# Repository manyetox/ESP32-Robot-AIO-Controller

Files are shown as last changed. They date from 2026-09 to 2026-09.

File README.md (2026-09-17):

# Robot AIO ESP32 Controller

**Compact all-in-one ESP32 controller for RC cars, mobile robots and small combat robots.**

This PCB was designed to replace the usual collection of an ESP32 development board, multiple motor-driver modules, voltage regulators and large amounts of wiring with a single compact controller.

The board integrates an **ESP32-WROOM-32UE**, **four independent brushed DC motor drivers**, onboard power regulation, battery-voltage monitoring, programming/debug connections and additional GPIO into a **50 × 46.2 mm PCB**.

The controller has been **manufactured, hand-assembled and fully tested**, and the finished board is operational.

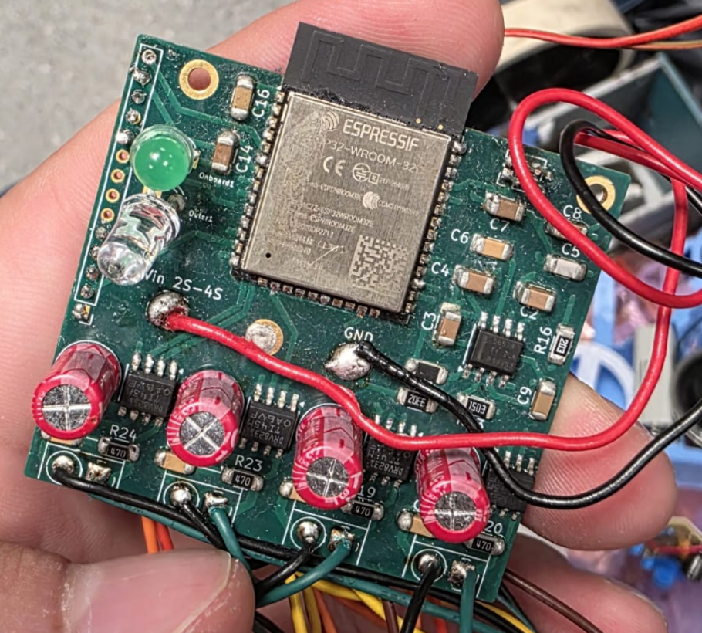
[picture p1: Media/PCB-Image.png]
Assembled Robot AIO Controller


> **Status:** Hardware tested and working
> **PCB:** 8-layer, 50 × 46.2 mm
> **Controller:** ESP32-WROOM-32UE
> **Motor channels:** 4 × bidirectional brushed DC
> **Battery:** 2S–4S
> **Application:** RC cars, mobile robots and small combat robots

---

## Why I Built This

Small competition robots often end up containing several separate modules:

* ESP32/Arduino development board
* multiple H-bridge motor drivers
* voltage regulator
* battery-monitoring circuit
* programming hardware
* connectors
* large amounts of point-to-point wiring

This works, but it takes space, adds failure points and makes the electrical system much harder to package cleanly inside a small robot.

The goal of **Robot AIO** was to integrate the essential electronics of a small mobile robot onto one board.

It was originally designed with **Robot Wars / combat robotics and RC-car projects** in mind, where compact packaging, fast assembly and simple motor control are particularly useful.

---

## Hardware Images

The final PCB shown above has been assembled and tested successfully. The repository also includes the design views below.

### PCB Layout

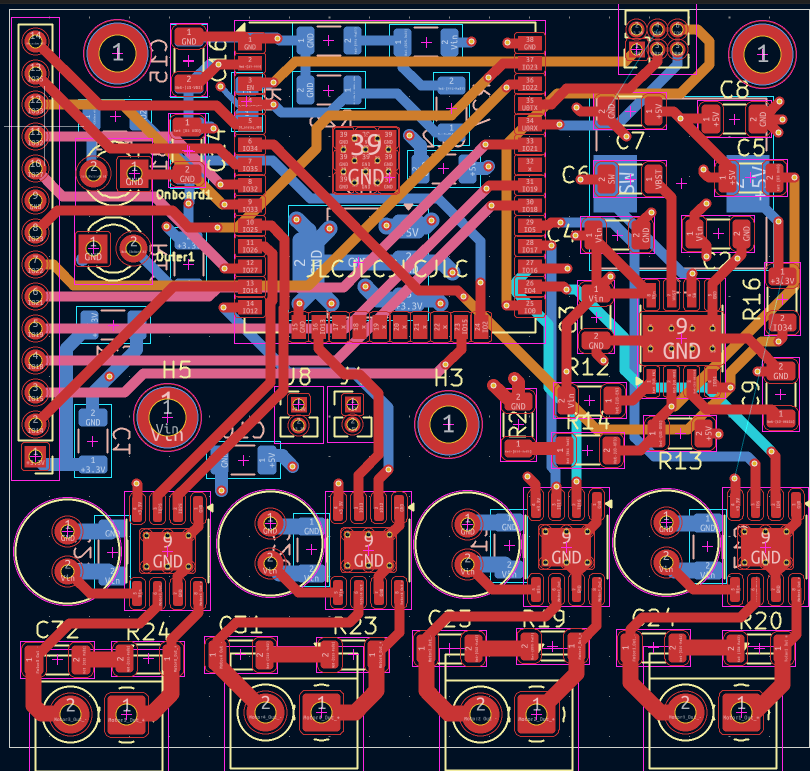
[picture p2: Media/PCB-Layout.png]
Eight-layer PCB layout


### Schematic

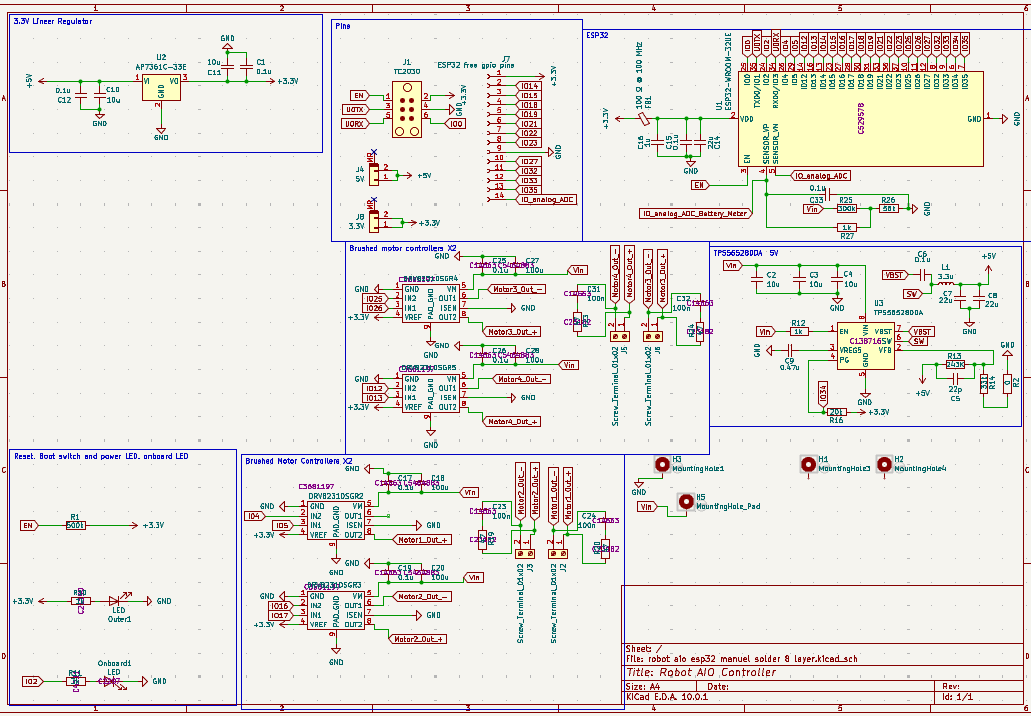
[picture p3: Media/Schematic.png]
Robot AIO controller schematic


> A demonstration video is not currently included in this repository. To add
> one later, place it in the `Media` directory and link it here.

---

# Features

### 4 Independent Brushed Motor Channels

The board contains **four DRV8231 H-bridge motor-driver stages**.

Each channel supports:

* forward rotation
* reverse rotation
* PWM speed control
* active braking
* independent ESP32 control

This makes the board suitable for configurations such as:

* 2-wheel differential drive
* 4-wheel differential drive
* skid-steer robots
* mecanum/omnidirectional platforms
* RC vehicles
* small combat robots
* other multi-motor robotic platforms

Each motor has its own 2-pin screw terminal.

---

## ESP32 Controller

The main processor is an:

**ESP32-WROOM-32UE**

This provides:

* dual-core ESP32 processing
* Wi-Fi
* Bluetooth
* hardware PWM
* ADC
* UART
* SPI
* I²C
* additional GPIO for sensors and peripherals

The **32UE** variant also allows an external antenna to be used, which is useful when the controller is mounted inside a robot with significant metal structure around it.

Possible control methods therefore include:

* Bluetooth gamepads
* phone control
* custom wireless controllers
* Wi-Fi control
* conventional RC receiver interfaces
* autonomous control

The exact control system is implemented in firmware rather than being locked into the PCB.

---

# Hardware Architecture

```text
                    2S–4S Battery
                         │
             ┌───────────┴───────────┐
             │                       │
             ▼                       ▼
       Motor Supply            TPS56528 Buck
             │                       │
             │                      3.3 V
             │                       │
     ┌───────┼────────┐              ▼
     │       │        │          ESP32-WROOM
     │       │        │              │
     ▼       ▼        ▼              │
   DRV1    DRV2     DRV3    DRV4    │
     │       │        │       │      │
     ▼       ▼        ▼       ▼      │
  Motor 1 Motor 2  Motor 3 Motor 4   │
                                    │
                         ┌──────────┴─────────┐
                         │                    │
                    Battery ADC         Expansion GPIO
```

The motor drivers operate directly from the battery rail while the ESP32 and logic circuitry are supplied by the regulated **3.3 V rail**.

---

# Motor GPIO Mapping

The four motor drivers are controlled directly by ESP32 GPIO.

| Motor | Input 1 | Input 2 | Output Connector |
| --- | ---: | ---: | --- |
| Motor 1 |  GPIO 4 |  GPIO 5 | J2 |
| Motor 2 | GPIO 16 | GPIO 17 | J3 |
| Motor 3 | GPIO 25 | GPIO 26 | J6 |
| Motor 4 | GPIO 12 | GPIO 13 | J5 |

Each channel can therefore be independently controlled using the ESP32 PWM peripherals.

For differential-drive robots, for example:

```text
Left Motors  → Motor 1 + Motor 2
Right Motors → Motor 3 + Motor 4
```

The assignment can of course be changed entirely in firmware.

---

# Motor Outputs

Each motor channel uses a **DRV8231 integrated H-bridge**.

The DRV8231 includes:

* integrated N-channel MOSFET H-bridge
* PWM control
* over-current protection
* thermal protection
* under-voltage lockout
* current regulation capability

The IC is rated for up to **3.7 A peak output current**.

> **Important:** 3.7 A is the motor-driver IC's peak rating, not a guaranteed continuous-current rating for the complete PCB. Practical continuous current depends on motor load, PCB temperature, cooling, battery voltage and operating conditions.

Always check the **stall current** of the motor rather than only its no-load/running current.

---

# Motor Noise Suppression

Brushed motors can generate significant electrical noise from commutation.

Each motor output therefore includes an RC suppression network consisting of approximately:

```text
47 Ω + 100 nF
```

across the motor output.

This helps suppress high-frequency switching and brush noise before it propagates through the rest of the robot electronics.

Additional suppression directly across the motor terminals may still be useful for particularly noisy motors.

---

# Power System

## Battery Input

The PCB was designed for:

**2S–4S battery systems**

Typical LiPo voltage range:

| Battery | Nominal | Fully Charged |
| --- | ---: | ---: |
| 2S | 7.4 V | 8.4 V |
| 3S |  11.1 V | 12.6 V |
| 4S |  14.8 V | 16.8 V |

Large solder pads are provided for the main:

```text
VIN
GND
```

connections.

This avoids passing the combined robot current through a small PCB connector.

---

## 3.3 V Regulator

The logic power supply is based around a **TPS56528 synchronous buck regulator**.

It converts the battery voltage directly to approximately:

```text
3.3 V
```

for the ESP32 and logic circuitry.

The regulator allows the controller to operate directly from the robot battery without requiring a separate external buck converter.

---

# Battery Voltage Monitoring

Battery voltage is measured directly by the ESP32 through an onboard resistor divider.

The divider uses approximately:

```text
300 kΩ
56 kΩ
```

with filtering before the ADC input.

The approximate relationship is:

```text
Vbattery ≈ Vadc × 6.36
```

For example:

```text
ADC = 2.00 V
Battery ≈ 12.7 V
```

This allows firmware to implement features such as:

* live battery telemetry
* low-voltage warnings
* reduced-power mode
* automatic shutdown behaviour
* battery percentage estimation

The battery-monitor ADC input is connected internally to the ESP32.

Because the ESP32 ADC is not a precision measurement device, calibration against a multimeter is recommended when accurate voltage readings are required.

---

# Expansion Header

A **14-pin 2.00 mm expansion header** exposes unused ESP32 connections.

| Pin | Signal |
| --: | --- |
| 1 | 3.3 V |
| 2 | GPIO 14 |
| 3 | GPIO 15 |
| 4 | GPIO 18 |
| 5 | GPIO 19 |
| 6 | GPIO 21 |
| 7 | GPIO 22 |
| 8 | GPIO 23 |
| 9 | GND |
|  10 | GPIO 27 |
|  11 | GPIO 32 |
|  12 | GPIO 33 |
|  13 | GPIO 35 |
|  14 | Analog ADC |

This makes it possible to add peripherals without modifying the controller PCB.

Examples include:

* IMUs
* encoders
* distance sensors
* servos
* limit switches
* LEDs
* current sensors
* RC receivers
* displays
* SPI devices
* I²C devices

---

# Programming Interface

A dedicated programming/debug header provides:

```text
EN
3.3 V
UART TX
GND
UART RX
GPIO 0
```

This allows the ESP32 to be programmed without permanently adding a USB-to-UART converter to the robot.

Keeping the USB interface off the main board saves both PCB space and components in the finished robot.

---

# LEDs

The PCB includes two LED functions.

### Power LED

One LED is connected to the **3.3 V supply** and provides a visual indication that the logic rail is powered.

### Programmable LED

A second LED is controlled by:

```text
GPIO 2
```

It can be used for:

* boot indication
* connection status
* controller pairing
* low-battery warning
* fault indication
* debugging

---

# PCB

The controller uses an **8-layer PCB**.

Dimensions:

```text
50.0 mm × 46.2 mm
```

PCB thickness:

```text
1.6 mm
```

The board includes multiple mounting holes and large ground/power areas to make mechanical installation into a robot easier.

The design was also intentionally created around components that could be **assembled manually**, allowing prototypes to be built without requiring professional PCBA.

---

# Example Applications

## RC Car

A basic RC vehicle can use:

```text
Gamepad / Phone
       │
   Bluetooth
       │
       ▼
     ESP32
     ┌──┴──┐
     ▼     ▼
 Left    Right
Motor    Motor
```

No external motor-driver module or microcontroller board is required.

---

## Four-Wheel Drive Robot

All four channels can be used independently:

```text
Motor 1 ─ Front Left
Motor 2 ─ Rear Left
Motor 3 ─ Front Right
Motor 4 ─ Rear Right
```

This is particularly useful for compact skid-steer robots.

---

## Combat Robot

For a small combat robot, the board can combine:

* wireless control
* drive-motor control
* battery monitoring
* status indication
* sensor interfaces

into a single PCB.

High-current weapon motors should normally use a separate appropriately rated ESC or motor controller.

---

# Design Goals

The project was built around several priorities:

### Compact

Replace several separate modules with one board.

### Simple Wiring

Battery, motors and peripherals connect directly to the controller.

### Flexible

The ESP32 allows the same PCB to be used for many different robot architectures.

### Repairable

The first prototypes were designed with manual assembly and debugging in mind.

### Competition Friendly

The controller is intended for robots where space, weight, reliability and fast repair are important.

---

# Tested Hardware

The manufactured prototype has been **assembled and tested successfully**.

Verified functionality includes the core controller hardware, power system and motor-control architecture.

See the [assembled working PCB](Media/PCB-Image.png), [PCB layout](Media/PCB-Layout.png), and [schematic](Media/Schematic.png) included in this repository.

This repository contains the design used to manufacture the working prototype.

---

# KiCad Design Files

The PCB was designed using **KiCad 9**.

Main project files include:

```text
robot aio esp32 manuel solder 8 layer.kicad_pro
robot aio esp32 manuel solder 8 layer.kicad_sch
robot aio esp32 manuel solder 8 layer.kicad_pcb
```

The repository therefore contains the editable schematic and PCB rather than only manufacturing outputs.

---

# Main Components

| Component | Function |
| --- | --- |
| ESP32-WROOM-32UE | Main processor / wireless controller |
| 4 × DRV8231 | Brushed DC motor H-bridges |
| TPS56528 | 3.3 V synchronous buck regulator |
| 3.3 µH Inductor | Buck-converter power stage |
| Motor screw terminals  | Four motor outputs |
| TC2030-style interface | ESP32 programming/debug |
| 14-pin header | GPIO expansion |
| Battery divider | Battery-voltage measurement |
| Status LEDs | Power and firmware indication |

---

# Repository Structure

The repository is organised as follows:

```text
ESP32-Robot-AIO-Controller/
│
├── README.md
│
├── Firmware/
│   └── phone_controlled_2servo.ino
│
├── Hardware/
│   └── robot aio esp32/
│       ├── fabrication-toolkit-options.json
│       ├── robot aio esp32 manuel solder 8 layer.kicad_pcb
│       ├── robot aio esp32 manuel solder 8 layer.kicad_prl
│       ├── robot aio esp32 manuel solder 8 layer.kicad_pro
│       └── robot aio esp32 manuel solder 8 layer.kicad_sch
│
└── Media/
    ├── PCB-Image.png
    ├── PCB-Layout.png
    └── Schematic.png
```

---

# Safety / Important Notes

This is an experimental robotics controller rather than a certified commercial motor controller.

When reproducing or modifying the design:

* verify battery polarity before applying power
* use an appropriately rated external fuse
* use a suitable emergency power-disconnect system for competition robots
* check motor stall current before connecting a motor
* provide adequate cooling for sustained high-current operation
* test the robot with the drive wheels off the ground before full-power operation
* implement a communication-loss failsafe in firmware
* follow the safety requirements of the relevant robotics competition

For combat robots in particular, the controller should form only one part of the complete electrical safety system.

---

# Project Status

**Working hardware.**

The first manufactured controller has been assembled and tested, and the PCB is functional.

Future development can include:

* example ESP32 firmware
* Bluetooth gamepad support
* RC receiver support
* configurable failsafe logic
* battery telemetry
* closed-loop wheel control using encoders
* additional robot-specific expansion modules

---

## About

Robot AIO was developed as a compact general-purpose electronics platform for my robotics projects, particularly **RC vehicles and combat robotics**.

The main idea was simple:

> **One PCB for the controller, power supply, motor drivers and robot I/O — instead of a box full of development boards and modules.**

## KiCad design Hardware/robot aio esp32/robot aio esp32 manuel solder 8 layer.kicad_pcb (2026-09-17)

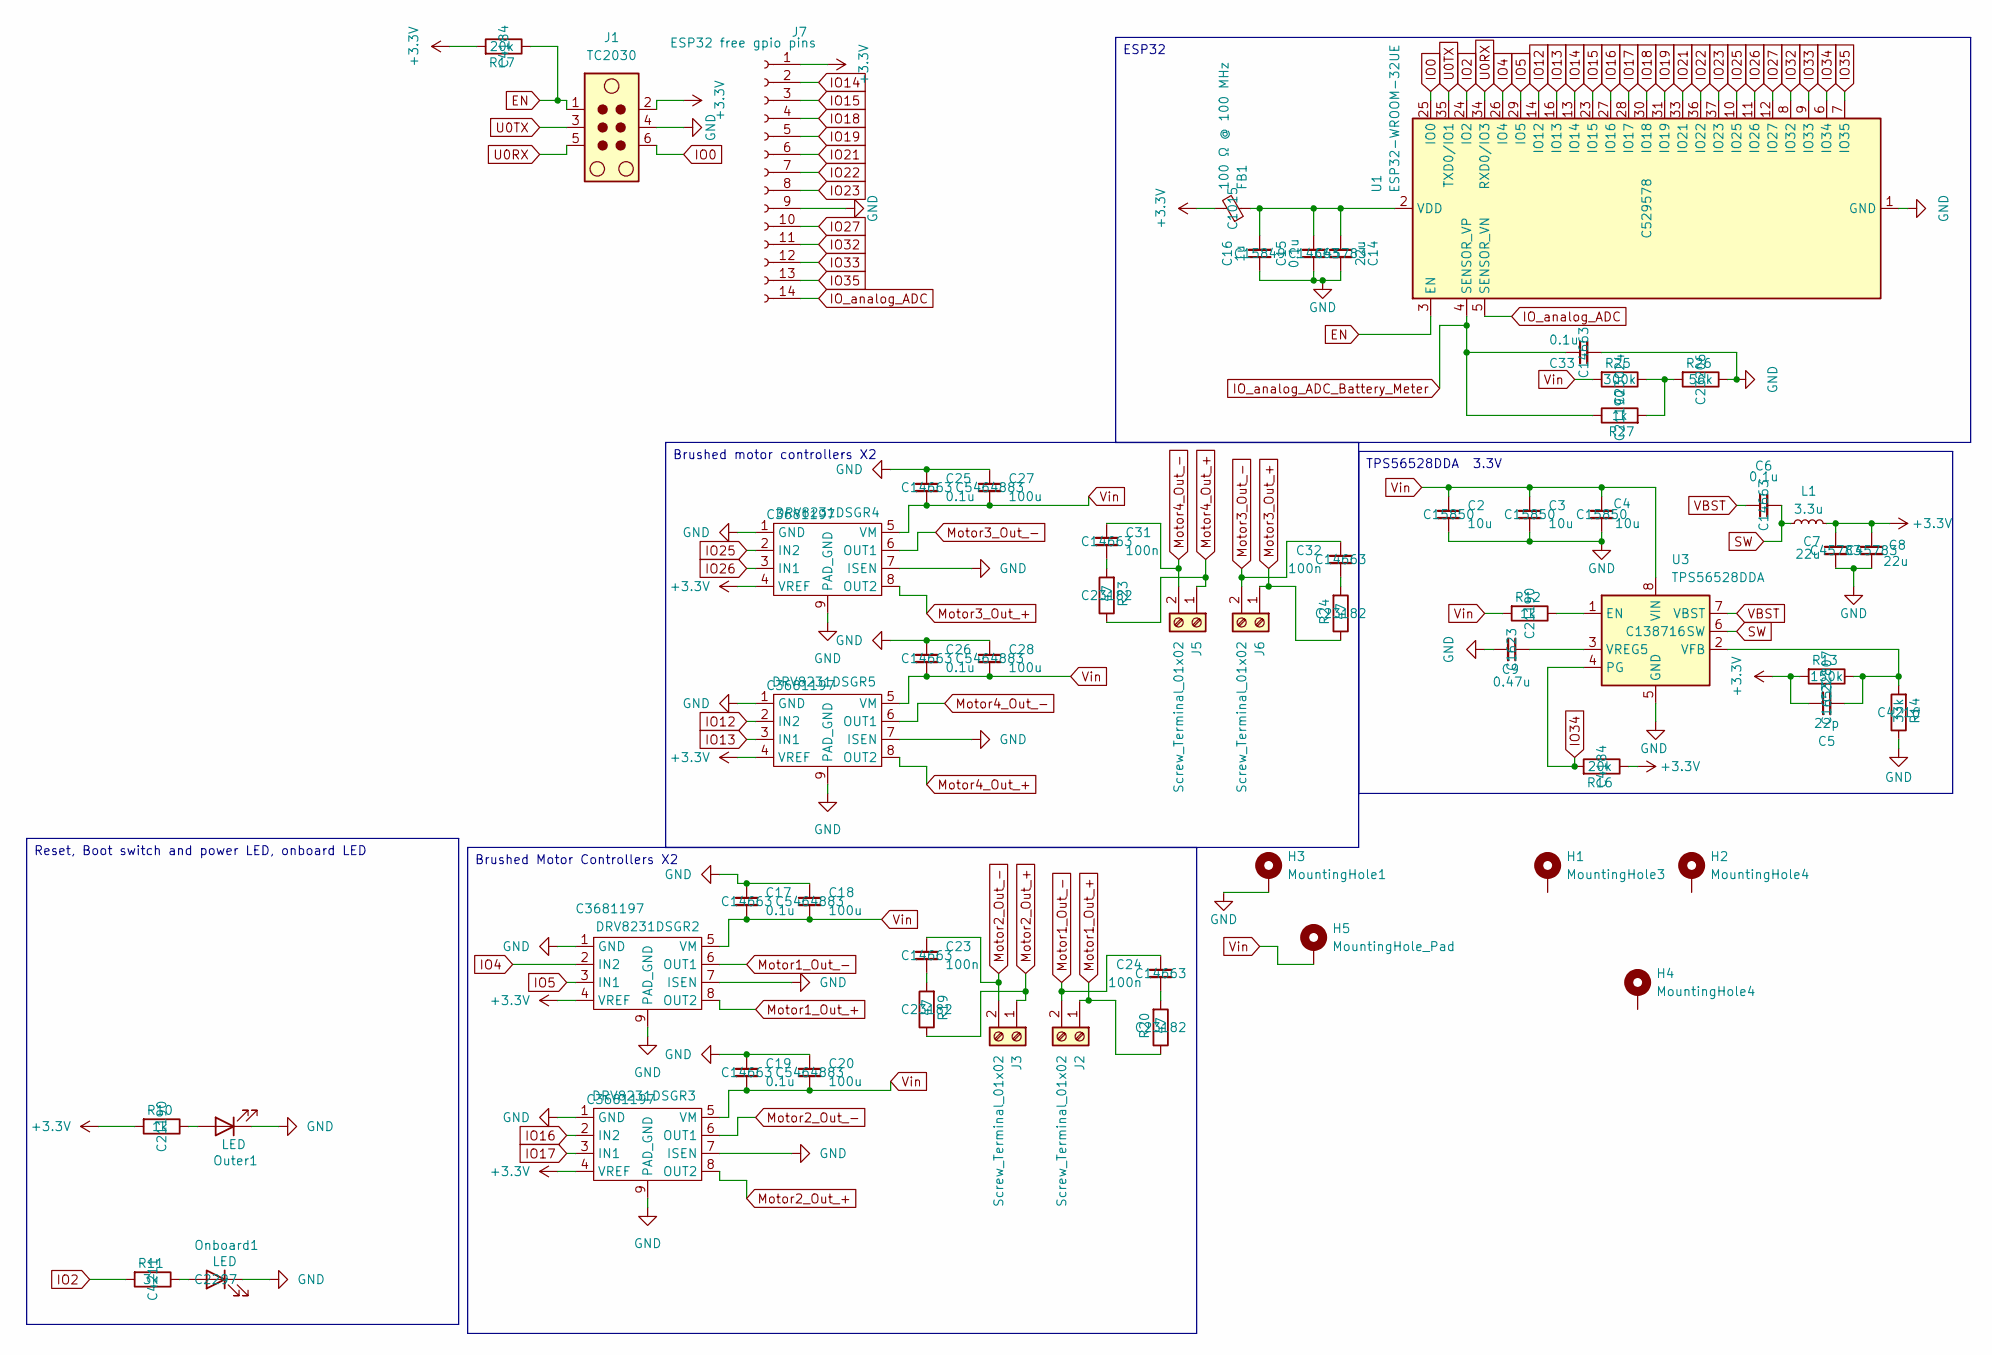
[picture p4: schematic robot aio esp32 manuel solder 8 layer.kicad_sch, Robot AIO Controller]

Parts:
C2, C3, C4: 10u; C_1206_3216Metric; LCSC Part # C15850
C5: 22p; C_1206_3216Metric; LCSC Part # C1653
C6, C15, C17, C19, C25, C26, C33: 0.1u; C_1206_3216Metric; LCSC Part # C14663
C7, C8, C14: 22u; C_1206_3216Metric; LCSC Part # C45783
C9: 0.47u; C_1206_3216Metric; LCSC Part # C1623
C16: 1u; C_1206_3216Metric; LCSC Part # C15849
C18, C20, C27, C28: 100u; C_Radial_D6.3mm_H5.0mm_P2.50mm; LCSC Part # C5464883
C23, C24, C31, C32: 100n; C_1206_3216Metric; LCSC Part # C14663
DRV8231DSGR2, DRV8231DSGR3, DRV8231DSGR4, DRV8231DSGR5: HSOP-8-1EP_3.9x4.9mm_P1.27mm_EP2.41x3.1mm_ThermalVias; LCSC Part # C3681197
FB1: 100 Ω @ 100 MHz; L_1206_3216Metric; LCSC Part # C1015
H1: MountingHole3; MountingHole_2.2mm_M2_DIN965_Pad_TopBottom
H2, H4: MountingHole4; MountingHole_2.2mm_M2_DIN965_Pad_TopBottom
H3: MountingHole1; MountingHole_2.2mm_M2_DIN965_Pad_TopBottom
H5: MountingHole_Pad; MountingHole_2.2mm_M2_DIN965_Pad_TopBottom
J1: TC2030; PinHeader_2x03_P1.27mm_Vertical
J2, J3, J5, J6: Screw_Terminal_01x02; TerminalBlock_4Ucon_1x02_P3.50mm_Horizontal
J7: ESP32 free gpio pins; PinHeader_1x14_P2.00mm_Vertical
L1: 3.3u; L_10.4x10.4_H4.8
Onboard1: LED; LED_D3.0mm; LCSC Part # C2297
Outer1: LED; LED_D3.0mm
R10, R12, R27: 1k; R_1206_3216Metric; LCSC Part # C21190
R11: 3k; R_1206_3216Metric; LCSC Part # C4211
R13: 150k; R_1206_3216Metric; LCSC Part # C22807
R14: 33k; R_1206_3216Metric; LCSC Part # C4216
R16, R17: 20k; R_1206_3216Metric; LCSC Part # C4184
R19, R20, R23, R24: 47; R_1206_3216Metric; LCSC Part # C23182
R25: 300k; R_1206_3216Metric; LCSC Part # C23024
R26: 56k; R_1206_3216Metric; LCSC Part # C23206
U1: ESP32-WROOM-32UE; LCSC Part # C529578
U3: TPS56528DDA; Texas_HSOP-8-1EP_3.9x4.9mm_P1.27mm_ThermalVias; LCSC Part # C138716

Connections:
+3.3V: C5.1, C7.1, C8.1, DRV8231DSGR2.4 (VREF), DRV8231DSGR3.4 (VREF), DRV8231DSGR4.4 (VREF), DRV8231DSGR5.4 (VREF), FB1.2, J1.2, J7.1, L1.2, R10.2, R13.2, R16.1, R17.2
EN: J1.1, R17.1, U1.3 (EN)
GND: C2.2, C3.2, C4.2, C7.2, C8.2, C9.2, C14.2, C15.1, C16.1, C17.1, C18.1, C19.1, C20.1, C25.1, C26.1, C27.1, C28.1, C33.2, DRV8231DSGR2.1 (GND), DRV8231DSGR2.7 (ISEN), DRV8231DSGR2.9 (PAD_GND), DRV8231DSGR3.1 (GND), DRV8231DSGR3.7 (ISEN), DRV8231DSGR3.9 (PAD_GND), DRV8231DSGR4.1 (GND), DRV8231DSGR4.7 (ISEN), DRV8231DSGR4.9 (PAD_GND), DRV8231DSGR5.1 (GND), DRV8231DSGR5.7 (ISEN), DRV8231DSGR5.9 (PAD_GND), H3.MP, J1.4, J7.9, Onboard1.1 (K), Outer1.1 (K), R14.1, R26.1, U1.1 (GND), U1.15 (GND), U1.38 (GND), U1.39 (GND), U3.5 (GND), U3.9 (GND)
IO0: J1.6, U1.25 (IO0)
IO2: R11.2, U1.24 (IO2)
IO4: DRV8231DSGR2.2 (IN2), U1.26 (IO4)
IO5: DRV8231DSGR2.3 (IN1), U1.29 (IO5)
IO12: DRV8231DSGR5.2 (IN2), U1.14 (IO12)
IO13: DRV8231DSGR5.3 (IN1), U1.16 (IO13)
IO14: J7.2, U1.13 (IO14)
IO15: J7.3, U1.23 (IO15)
IO16: DRV8231DSGR3.2 (IN2), U1.27 (IO16)
IO17: DRV8231DSGR3.3 (IN1), U1.28 (IO17)
IO18: J7.4, U1.30 (IO18)
IO19: J7.5, U1.31 (IO19)
IO21: J7.6, U1.33 (IO21)
IO22: J7.7, U1.36 (IO22)
IO23: J7.8, U1.37 (IO23)
IO25: DRV8231DSGR4.2 (IN2), U1.10 (IO25)
IO26: DRV8231DSGR4.3 (IN1), U1.11 (IO26)
IO27: J7.10, U1.12 (IO27)
IO32: J7.11, U1.8 (IO32)
IO33: J7.12, U1.9 (IO33)
IO34: R16.2, U1.6 (IO34), U3.4 (PG)
IO35: J7.13, U1.7 (IO35)
IO_analog_ADC: J7.14, U1.5 (SENSOR_VN)
IO_analog_ADC_Battery_Meter: C33.1, R27.1, U1.4 (SENSOR_VP)
Motor1_Out_+: DRV8231DSGR2.8 (OUT2), J2.1, R20.1
Motor1_Out_-: C24.1, DRV8231DSGR2.6 (OUT1), J2.2
Motor2_Out_+: DRV8231DSGR3.8 (OUT2), J3.1, R19.1
Motor2_Out_-: C23.1, DRV8231DSGR3.6 (OUT1), J3.2
Motor3_Out_+: DRV8231DSGR4.8 (OUT2), J6.1, R24.1
Motor3_Out_-: C32.1, DRV8231DSGR4.6 (OUT1), J6.2
Motor4_Out_+: DRV8231DSGR5.8 (OUT2), J5.1, R23.1
Motor4_Out_-: C31.1, DRV8231DSGR5.6 (OUT1), J5.2
unnamed: C23.2, R19.2
unnamed: C24.2, R20.2
unnamed: C31.2, R23.2
unnamed: C32.2, R24.2
unnamed: Onboard1.2 (A), R11.1
unnamed: Outer1.2 (A), R10.1
unnamed: R25.1, R26.2, R27.2
unnamed: C14.1, C15.2, C16.2, FB1.1, U1.2 (VDD)
unnamed: R12.1, U3.1 (EN)
unnamed: C5.2, R13.1, R14.2, U3.2 (VFB)
unnamed: C9.1, U3.3 (VREG5)
SW: C6.2, L1.1, U3.6 (SW)
U0RX: J1.5, U1.34 (RXD0/IO3)
U0TX: J1.3, U1.35 (TXD0/IO1)
VBST: C6.1, U3.7 (VBST)
Vin: C2.1, C3.1, C4.1, C17.2, C18.2, C19.2, C20.2, C25.2, C26.2, C27.2, C28.2, DRV8231DSGR2.5 (VM), DRV8231DSGR3.5 (VM), DRV8231DSGR4.5 (VM), DRV8231DSGR5.5 (VM), H5.1 (1_1), R12.2, R25.2, U3.8 (VIN)

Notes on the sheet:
ESP32
Brushed Motor Controllers X2
Brushed motor controllers X2
Reset, Boot switch and power LED, onboard LED
TPS56528DDA 3.3V

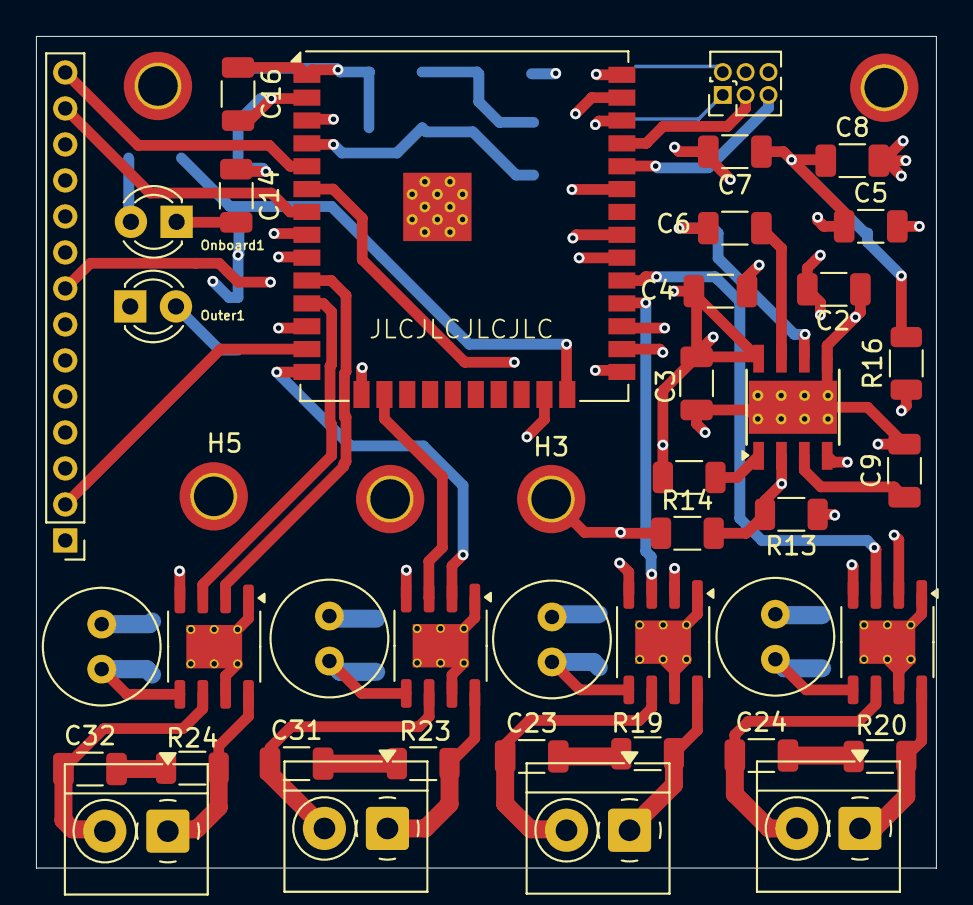
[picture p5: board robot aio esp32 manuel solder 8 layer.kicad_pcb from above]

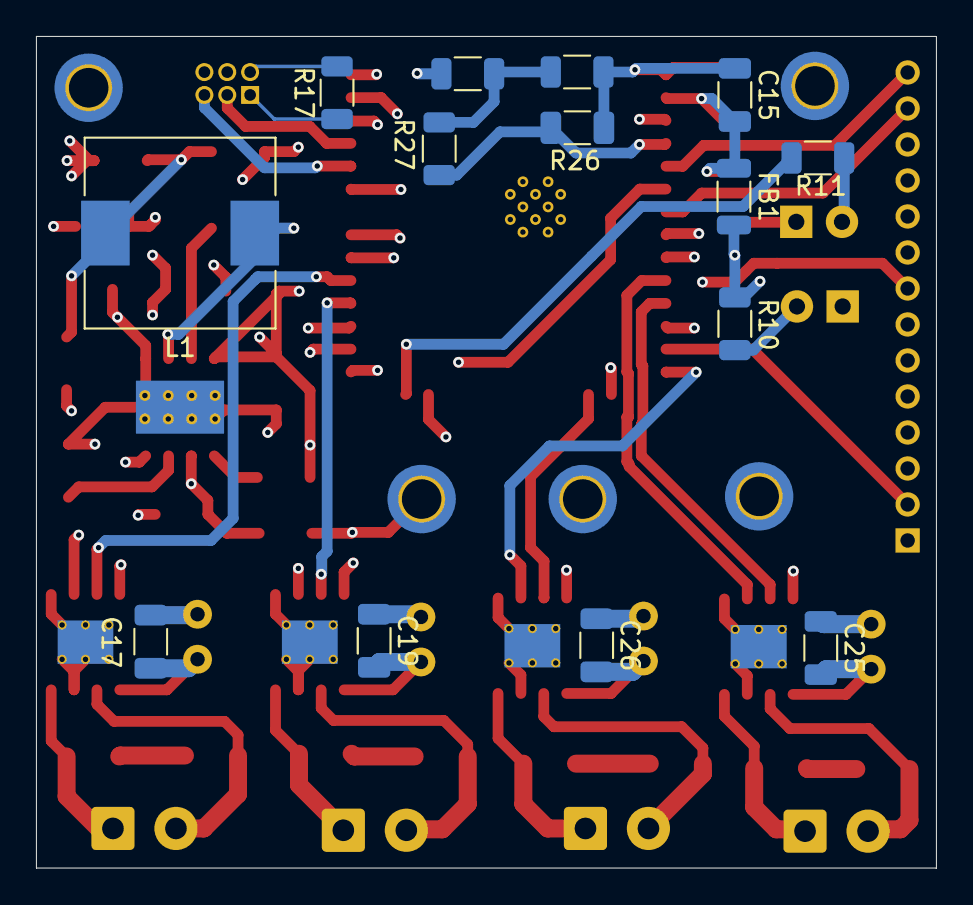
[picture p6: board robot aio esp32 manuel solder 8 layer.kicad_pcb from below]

Board: 8 copper layers, 50.0 x 46.2 mm, 59 parts (14 on the bottom side), 51 nets.

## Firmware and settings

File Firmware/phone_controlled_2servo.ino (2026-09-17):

#include <WiFi.h>
#include <WebServer.h>

// --- Configuration ---
const char* ssid = "My_RC_Car";
const char* password = "password123";

WebServer server(80);

// --- Motor Pin Setup ---
const int m1Pin1 = 25; const int m1Pin2 = 26;
const int m2Pin1 = 12; const int m2Pin2 = 13;
const int m3Pin1 = 4;  const int m3Pin2 = 5;
const int m4Pin1 = 16; const int m4Pin2 = 17;

// --- Servo Pin Setup (From your schematic) ---
const int servo1Pin = 27; // Pin 10 on your J7 connector
const int servo2Pin = 32; // Pin 11 on your J7 connector

// --- PWM Settings ---
// Motors
const int motorFreq = 30000;
const int motorRes = 8;
// Servos (Must be 50Hz)
const int servoFreq = 50;
const int servoRes = 14; // Higher resolution for smooth movement

// PWM Channels (0-15 available)
// Motors use 0-7
const int c1a=0, c1b=1; 
const int c2a=2, c2b=3; 
const int c3a=4, c3b=5; 
const int c4a=6, c4b=7;
// Servos use 8-9
const int cServo1 = 8;
const int cServo2 = 9;

// --- HTML Interface ---
const char* htmlPage = R"html(
<!DOCTYPE html>
<html>
<head>
<meta name="viewport" content="width=device-width, initial-scale=1, maximum-scale=1, user-scalable=no">
<style>
  body { 
    background-color: #222; margin: 0; 
    display: flex; flex-direction: column; align-items: center; 
    font-family: sans-serif; color: white;
    height: 100vh; overflow: hidden;
  }
  h3 { margin: 10px 0 5px 0; pointer-events: none; }
  
  /* Joystick Styles */
  #joystick-zone {
    width: 260px; height: 260px;
    background: radial-gradient(circle, #444 0%, #222 60%);
    border: 2px solid #555; border-radius: 50%;
    position: relative; touch-action: none; margin-bottom: 20px;
  }
  #knob {
    width: 70px; height: 70px;
    background: #4CAF50; border-radius: 50%;
    position: absolute; top: 50%; left: 50%;
    transform: translate(-50%, -50%);
    box-shadow: 0 0 15px rgba(0,0,0,0.5); pointer-events: none;
  }

  /* Slider Styles */
  .slider-container {
    width: 80%; max-width: 400px;
    background: #333; padding: 10px; margin: 5px;
    border-radius: 10px; display: flex; align-items: center;
  }
  .slider-label { width: 70px; font-weight: bold; font-size: 14px; }
  input[type=range] { flex-grow: 1; height: 30px; }
</style>
</head>
<body>

  <div class="slider-container">
    <div class="slider-label">Servo 1</div>
    <input type="range" min="0" max="180" value="90" oninput="sendServo(1, this.value)">
  </div>
  <div class="slider-container">
    <div class="slider-label">Servo 2</div>
    <input type="range" min="0" max="180" value="90" oninput="sendServo(2, this.value)">
  </div>

  <h3>Drive</h3>
  <div id="joystick-zone">
    <div id="knob"></div>
  </div>

<script>
  // Joystick Logic
  const zone = document.getElementById('joystick-zone');
  const knob = document.getElementById('knob');
  const maxDist = 90; 
  let rect = zone.getBoundingClientRect();
  let dragging = false;

  zone.addEventListener('touchstart', startMove);
  zone.addEventListener('touchmove', moveKnob);
  zone.addEventListener('touchend', endMove);
  zone.addEventListener('mousedown', (e) => { dragging=true; startMove(e); });
  window.addEventListener('mousemove', (e) => { if(dragging) moveKnob(e); });
  window.addEventListener('mouseup', () => { if(dragging) { dragging=false; endMove(); }});

  function startMove(e) { e.preventDefault(); rect = zone.getBoundingClientRect(); }
  
  function moveKnob(e) {
    e.preventDefault();
    let clientX = e.touches ? e.touches[0].clientX : e.clientX;
    let clientY = e.touches ? e.touches[0].clientY : e.clientY;
    let x = clientX - (rect.left + rect.width/2);
    let y = clientY - (rect.top + rect.height/2);
    
    let dist = Math.sqrt(x*x + y*y);
    if (dist > maxDist) { x = (x/dist)*maxDist; y = (y/dist)*maxDist; }
    
    knob.style.transform = `translate(calc(-50% + ${x}px), calc(-50% + ${y}px))`;
    
    let normX = Math.round((x / maxDist) * 255);
    let normY = Math.round((y / maxDist) * 255) * -1;
    sendDrive(normX, normY);
  }

  function endMove() {
    knob.style.transform = `translate(-50%, -50%)`;
    sendDrive(0, 0);
  }

  let lastDrive = 0;
  function sendDrive(x, y) {
    let now = Date.now();
    if (now - lastDrive > 50 || (x===0 && y===0)) {
      lastDrive = now;
      fetch(`/drive?x=${x}&y=${y}`).catch(e=>{});
    }
  }

  // Servo Logic
  function sendServo(id, val) {
    fetch(`/servo?id=${id}&val=${val}`).catch(e=>{});
  }
</script>
</body>
</html>
)html";

void setup() {
  Serial.begin(115200);

  // --- Motor Setup ---
  ledcSetup(c1a, motorFreq, motorRes); ledcAttachPin(m1Pin1, c1a);
  ledcSetup(c1b, motorFreq, motorRes); ledcAttachPin(m1Pin2, c1b);
  ledcSetup(c2a, motorFreq, motorRes); ledcAttachPin(m2Pin1, c2a);
  ledcSetup(c2b, motorFreq, motorRes); ledcAttachPin(m2Pin2, c2b);
  ledcSetup(c3a, motorFreq, motorRes); ledcAttachPin(m3Pin1, c3a);
  ledcSetup(c3b, motorFreq, motorRes); ledcAttachPin(m3Pin2, c3b);
  ledcSetup(c4a, motorFreq, motorRes); ledcAttachPin(m4Pin1, c4a);
  ledcSetup(c4b, motorFreq, motorRes); ledcAttachPin(m4Pin2, c4b);

  // --- Servo Setup ---
  ledcSetup(cServo1, servoFreq, servoRes); 
  ledcAttachPin(servo1Pin, cServo1);
  
  ledcSetup(cServo2, servoFreq, servoRes); 
  ledcAttachPin(servo2Pin, cServo2);

  // Set default position (90 degrees)
  writeServo(cServo1, 90);
  writeServo(cServo2, 90);

  // Wi-Fi
  WiFi.softAP(ssid, password);
  Serial.print("IP: "); Serial.println(WiFi.softAPIP());

  // Server
  server.on("/", []() { server.send(200, "text/html", htmlPage); });
  server.on("/drive", handleDrive);
  server.on("/servo", handleServo);
  server.begin();
}

void loop() {
  server.handleClient();
}

// --- Servo Helper Function ---
// Calculates the correct PWM duty cycle for a servo at 50Hz
void writeServo(int channel, int angle) {
  // Map angle (0-180) to pulse width (500us - 2400us)
  int microsec = map(angle, 0, 180, 500, 2400);
  // Calculate Duty Cycle for 14-bit resolution (2^14 = 16384)
  // Period at 50Hz is 20000 microseconds
  int duty = (microsec * 16384) / 20000; 
  ledcWrite(channel, duty);
}

void handleServo() {
  if (server.hasArg("id") && server.hasArg("val")) {
    int id = server.arg("id").toInt();
    int val = server.arg("val").toInt();
    
    if (id == 1) writeServo(cServo1, val);
    if (id == 2) writeServo(cServo2, val);
    
    server.send(200, "text/plain", "OK");
  } else {
    server.send(400, "text/plain", "Error");
  }
}

// --- Motor Logic ---
void handleDrive() {
  if (server.hasArg("x") && server.hasArg("y")) {
    int x = server.arg("x").toInt(); 
    int y = server.arg("y").toInt(); 
    int left = constrain(y + x, -255, 255);
    int right = constrain(y - x, -255, 255);

    setMotorGroup(c1a, c1b, c3a, c3b, left);
    setMotorGroup(c2a, c2b, c4a, c4b, right);
    server.send(200, "text/plain", "OK");
  }
}

void setMotorGroup(int fA, int fB, int rA, int rB, int spd) {
  int pwm = abs(spd);
  if (spd > 0) {
    ledcWrite(fA, pwm); ledcWrite(fB, 0); ledcWrite(rA, pwm); ledcWrite(rB, 0);
  } else if (spd < 0) {
    ledcWrite(fA, 0); ledcWrite(fB, pwm); ledcWrite(rA, 0); ledcWrite(rB, pwm);
  } else {
    ledcWrite(fA, 0); ledcWrite(fB, 0); ledcWrite(rA, 0); ledcWrite(rB, 0);
  }
}

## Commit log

2026-09-17 Revise README for Robot AIO ESP32 Controller
    Updated README to reflect new project name and detailed features.
2026-09-17 updated with files v1
    [robot aio esp32 manuel solder 8 layer.kicad_pcb, robot aio esp32 manuel solder 8 layer.kicad_sch]
